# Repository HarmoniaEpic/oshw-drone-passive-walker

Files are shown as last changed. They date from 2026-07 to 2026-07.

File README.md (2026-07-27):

# Drone-Stabilized Passive Dynamic Walker（ドローン安定化受動歩行機）

**An open-source hardware concept: a McGeer-type passive dynamic walker whose
inverted-pendulum instability is converted into stable upright-pendulum
oscillation by an overhead stabilizing wrench — active thrust (Gen‑1) or
partial buoyancy (Gen‑2/3) — while the walking energy itself comes from
passive pendulum dynamics.**

> "A non-flying airship with legs."



---

## English summary

Passive dynamic walkers (McGeer 1990) are energy-efficient but unstable:
the stance phase is a divergent inverted pendulum. This project demonstrates,
in contact-accurate simulation (PyBullet, 1200 Hz event-driven control),
three generations of a machine that keeps the passive limit cycle intact and
stabilizes **attitude only** from above the virtual pivot point:

| Gen | Stabilizer | Propulsion | Key result |
|-----|---|---|---|
| 1 | Quadrotor attitude PD (**zero altitude support**, KZ=0) | Horizontal thrust (KV≥4–5) | 10 strikes / 8 s / 0.32 m/s sustained walking |
| 2 | Passive buoyancy (spherical He envelope on mast) | Azimuth ducted fan pair | Operating window **37–94 %W**; gait collapses by ground-force loss (~98 %W) *before* float-off (102 %W) |
| 3 | Passive buoyancy (airship hull + cruciform tail damping) | Azimuth ducted fan pair | 52 %W recommended; tail adds pitch/yaw damping & weathervane potential |
| 4 | **Mass geometry only** (water-ballasted feet, h_com < R, one-way "half-kamaboko" rocker soles) | Water transfer between feet + pump-charged drive bellows through a clock-escapement crank | 6 steps / +2.17 m / 40 s on flat ground, zero falls, body pitch within ±0.4°; crank quantized to half-turns |
| 5 | Mass geometry + "kamae" stance (crank-mounted tanks settle into a one-foot-raised ready pose) | **Water transfer only** — tanks ride the crank, hollow arms are the conduit, hub pump/valve; the whole body somersaults over the stance leg (dankaeri-faithful) | Fall-free 90 s / +0.43 m conservative gait (2 flips then parks); fast mode +1.93 m / 17.8 s (0.11 m/s); root limitation identified: uncontrolled leg attitude |
| 6 | Mass geometry + **gear-locked parallelogram legs** (each leg guided by two same-phase cranks 0.20 m apart; a 3-gear train on the leg locks the linkage through its dead center) | Water transfer only — the tank crank alone somersaults, the body stays upright; phase-synchronized transfer (SETTLE→CHARGE→FLIP) | **Zero falls over the whole pump range** (Q 0.15–0.50); best 18 steps / +2.42 m / 90 s, exact kinematic stride 2·RC = 0.134 m/step, body pitch ≤ 7° |

Distinct from BALLU (UCLA, buoyant body anchored by feet; patent application
US2018/0370040A1 **abandoned 2021**): here buoyancy is deliberately partial
(≈52 % of weight) so the legs stay loaded and heel-strike pendulum dynamics
— the energy mechanism — survive.

Everything here is simulation-validated design data: CAD, engineering
drawings, physics/control source, gait trajectories, and videos. No physical
prototype has been built yet — treat the BOM as a reference design.

## コンセプト（日本語）

受動歩行の振り子効率をドローンに持ち込み、倒立振り子の発散モードを
「上の支点から吊られた正立振り子」の振動モードに転換する。核心は3点：

1. **姿勢のみの上方安定化** — 高度支持ゼロ（KZ=0）でも歩行が成立する。
   安定化は帯域（Gen‑1）または浮心配置の幾何（Gen‑2/3）で払い、エネルギーでは払わない。
2. **部分浮力の適正窓** — 浮力37〜94%W。下限は姿勢発散、上限は浮上（102%W〜）より
   先に来る**接地力喪失による歩容崩壊**（98%W〜）。推奨52%Wで脚に体重の約半分を残し
   摩擦余裕を確保する。
3. **水平推力＝坂の代替** — ヒールストライク損失の補填はファンの水平推力
   （機械仕事0.1W級）のみ。同機体の単独飛行（誘導パワー約186W）に対し3〜4桁小さい。

## Repository layout

```
hardware/
  cad/        FreeCAD sources (.FCStd) + neutral STEP exports, Gen 1–6
  drawings/   A4 engineering drawings (PDF): assembly + parts, 21 sheets
sim/          Physics & control source of truth (PyBullet) + recorded gaits
  walker_pybullet.py   Gen-1  (usage: python walker_pybullet.py out.json <KZ> <KV>)
  walker_balloon.py    Gen-2  (usage: python walker_balloon.py out.json <B_N> [KV])
  walker_airship.py    Gen-3  (usage: python walker_airship.py out.json <B_N> [KV])
  walker_dankaeri5.py  Gen-4  (usage: python walker_dankaeri5.py out.json SLOPE_DEG
                       PUMP_PA [F_WIND] [E_MIN] [M_W] [P_BEL] [V_MAXB];
                       walker_dankaeri4.py is the earlier Gen-4 iteration)
  walker_gen5.py       Gen-5  (usage: python walker_gen5.py out.json SLOPE_DEG
                       Q_PUMP [M_W] [OM_V] [T_END] [R_T] [D_EXTRA] [BRAKES]
                       [C_CRK] [X_TOE] [Q_LIM] [FLIPLOCK] [R_TOE] [FOOT_REV])
  walker_gen6.py       Gen-6  (usage: python walker_gen6.py out.json SLOPE_DEG
                       Q_PUMP [M_W] [OM_V] [T_END] [R_T] [D_EXTRA] [-] [C_CRK]
                       [X_TOE] [-] [-] [R_TOE] [FOOT_REV] [PHASECTL] [DZ_T]
                       [RATCHET] [RC] [SLACK] [HEEL_HX]; reference config:
                       0 0.30 1.2 2.0 90 0.355 0.30 0 0.30 0.10 0 0 0.55 0 1
                       0.290 1 0.07 0.15 0.14)
  walk_traj_*.json     gait logs (base pose, joint angles, contact forces)
docs/         Concept note, per-generation design documents, BOM
media/        Walking videos (one per generation)
viz/          Blender visualization rigs (kinematic playback of sim output)
LICENSES/     Full license texts
```

## Reproducing the results

```
python -m venv pybullet-venv
pybullet-venv/bin/pip install pybullet numpy
pybullet-venv/bin/python sim/walker_pybullet.py out.json 0 5     # Gen-1: KZ=0, KV=5
pybullet-venv/bin/python sim/walker_balloon.py  out.json 13      # Gen-2: B=13 N
pybullet-venv/bin/python sim/walker_airship.py  out.json 13      # Gen-3: B=13 N
```

Each run prints strike count, distance, max pitch and mean fan force, and
writes a 60 Hz trajectory JSON. The Blender rigs in `viz/` replay these
trajectories as kinematic keyframes (Blender is visualization only; the
physics source of truth is `sim/`).

## Licensing（3層構成）

| Layer | Files | License | SPDX |
|---|---|---|---|
| Hardware design | `hardware/**` | CERN Open Hardware Licence v2 — Strongly Reciprocal | `CERN-OHL-S-2.0` |
| Source code | `sim/**` | MIT | `MIT` |
| Documentation & media | `docs/**`, `media/**`, `README.md` | Creative Commons BY-SA 4.0 | `CC-BY-SA-4.0` |

Full texts in [`LICENSES/`](LICENSES/). When adding files, put an SPDX
header in each source file, e.g. `# SPDX-License-Identifier: MIT`.

## Prior art & defensive publication

This design is published as open-source hardware; **no patent will be
sought**, and this repository (archived with a DOI on Zenodo — see
`docs/DEFENSIVE_PUBLICATION.md`) serves as defensive prior art for the
concepts listed above.

Key prior art acknowledged:

- T. McGeer, "Passive Dynamic Walking," *IJRR* 9(2), 1990.
- S. Collins, M. Wisse, A. Ruina, "A Three-Dimensional Passive-Dynamic
  Walking Robot with Two Legs and Knees," *IJRR* 20(7), 2001.
- H.-M. Maus et al., "Upright human gait did not provide a major mechanical
  challenge for our ancestors," *Nature Communications* 1:70, 2010
  (virtual pivot point).
- UCLA RoMeLa, BALLU / BALLU2 (buoyancy-assisted biped);
  US2018/0370040A1 (abandoned 2021), WO2017/087987A1.
- Traditional karakuri "dankaeri" tumbling doll (liquid-shift somersault
  automaton) — mechanism reference for Gen-4/5/6.
- Classic parallel-crank (side-rod) motion — locomotive coupling rods and
  wind-up walking toys — and gear-synchronized parallelogram guidance:
  mechanism references for the Gen-6 leg-attitude lock.

## Status / OSHW

- [x] Zenodo DOI: [10.5281/zenodo.21629977](https://doi.org/10.5281/zenodo.21629977)
- [ ] OSHWA self-certification (JP): *pending — apply after first tagged release*
- Simulation-validated; no physical build yet. Real-scale note: B=13 N of
  helium lift requires ≈1.3 m³ (sphere Ø≈1.4 m); the modeled envelopes are
  intentionally idealized.

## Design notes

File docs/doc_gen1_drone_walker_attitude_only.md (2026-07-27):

# 第1世代：クアッドロータ安定化受動歩行機（attitude-only 構成）

**対応ファイル**: `gen1_drone_walker_attitude_only.blend` / `walker_pybullet.py` /
`walk_traj_attitude_only.json` / `drone_walker_attitude_only.mp4`

---

## 1. 概要

受動歩行機（膝付き4脚・McGeer型）の股関節台座にクアッドロータを一体化した初代構成。
「移動エネルギーは脚の振り子力学、安定化はドローンの飛行制御」という役割分担を
最初に実証した世代。段階的な補正削減試験により、ドローンの必須機能が
**姿勢制御と水平推力（エネルギー補給）のみ**であることを特定した。

## 2. 機体構成

| 要素 | 仕様 |
|---|---|
| トルソ | 股関節車軸＋矩形台座＋対角4アーム先端ロータ（低重心配置・台座上面は上半身搭載用に確保）、1.2 kg |
| 大腿 | 各 0.22 kg、長さ 0.40 m、股関節はフリーヒンジ（完全受動） |
| 下腿 | 各 0.20 kg、長さ 0.40 m、膝は反張ストッパ（+0.08 rad）付き |
| 足 | 半径 0.12 m の円弧足（脚長の15%）、下腿軸から前方 0.04 m オフセット |
| 総質量 | 2.24 kg（総重量 22.0 N） |

**設計の要点**
- 円弧足の前方オフセットは床反力線を膝軸の前に通し、立脚中の膝を
  ストッパへ押し付け続ける座屈防止機構（実機文献と同じ手法）
- 外側大腿ペアの連結は股関節軸上を跨ぐヨークアーチとし、内脚可動域との干渉を回避

## 3. 制御アーキテクチャ（イベント駆動・1200 Hz）

| 系 | 実装 |
|---|---|
| センサー | 足別接地法線力、関節角・角速度 |
| ヒールストライク判定 | 遊脚接地力 > 8 N かつ 遊脚股関節角 < −0.08 rad かつ 遊脚時間 > 0.2 s |
| 膝ラッチ | 立脚＝強保持（300 N·m 上限で 0.08 rad へ）。遊脚＝トーオフ折りパルス（0.18 s、上限 1.5 N·m）→ 自由屈曲 → 股関節角 −0.10 rad 通過で再伸展 |
| ドローンFC | 姿勢PD（kp 80 / kd 10）＋速度追従（kv 5、目標 0.38 m/s）。**高度支持なし（KZ=0）** |

## 4. 実験結果（最終構成）

- **10歩連続・8秒・転倒なし**、平均 0.32 m/s
- 歩行周期 0.72 / 0.91 s の交互（周期2リミットサイクル）
- 平均推進力 0.31 N、推進の機械仕事 0.1 W 級
- 補正削減スイープの結論：高度支持は 400 N/m → 0 まで完全撤廃可能。
  速度補給ゲイン KV ≥ 4–5 が下限（KV=3 では高度支持の量に関係なく2歩で転倒）
  ＝ 平地では推力がヒールストライク損失を補填するエネルギー源であることの定量的裏付け

**エネルギー比較**：同機体を単体飛行させる場合の誘導パワー約186 W（電気入力 ~265 W）に対し、
歩行アシストの機械仕事は3〜4桁小さい。実機換算でも10〜50倍の節約見積り。

## 5. 開発過程で確定した知見

1. 遊脚が支持脚と平行になる瞬間の接地（toe scuffing）は直脚系の本質的欠陥で、
   膝機構＋トーオフ折りパルスがなければ2歩目が出ない
2. 一定剛性の膝バネでは立脚座屈防止と遊脚屈曲が両立不可能 → 状態依存ラッチが必須
3. 発進は死点（静的平衡）からではなく、関節角速度込みの歩行中間状態から与える
4. 定速クランプは振り子交換を殺す — 速度制御は平均への緩い補給に留める

## 6. 制約・注意

- 姿勢安定は能動制御（FC帯域）に依存。制御停止＝即転倒（発散時定数 ~0.27 s）
- .blend はキネマティック再生の可視化リグ。物理の原本は `walker_pybullet.py`
  （KZ / KV を CLI 引数で変更可能：`python walker_pybullet.py out.json <KZ> <KV>`）
- PyBullet モデルは脚ペアを面内1本に縮約した2D拘束相当（横方向は代理拘束）

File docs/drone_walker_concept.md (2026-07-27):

# ドローン安定化受動歩行機 — コンセプトノート

**日付**: 2026-07-27
**状態**: シミュレーション実証済み（PyBullet 1200 Hz / Blender 可視化）

---

## 1. 概要

受動歩行機（passive dynamic walker）の上部にマルチロータを一体化し、
**移動エネルギーは脚の振り子力学、安定化はドローンの飛行制御**という分担で
平地を歩行させる機体コンセプト。シミュレーションで持続歩行（10歩・8秒・転倒なし）を実証した。

## 2. 着想の核

### 2.1 振り子効率のドローンへの導入

ローター揚力は重力と常時対抗し続けるため誘導パワーを払い続ける。
一方、歩行は運動エネルギーと位置エネルギーを振り子交換で往復させ、
支払いはヒールストライクの衝突損失のみ。
飛行・歩行ハイブリッド機の歩行側を**完全受動脚**とすることで、
歩行モードのアクチュエータコストをほぼゼロにできる。

### 2.2 倒立振り子の「正立振り子化」（本コンセプトの肝）

- 立脚は倒立振り子であり、固有値 +√(g/ℓ) の発散モードを持つ
  （ℓ≈0.72 m → 発散時定数 ≈ 0.27 s）
- 重心**上方**に搭載したドローンが安定化レンチ（姿勢トルク＋復元力）を
  供給すると、発散モードは振動モードに転換され、系は「上の支点から
  吊られた正立振り子」と等価な安定構造になる
- ヒト歩行の **Virtual Pivot Point**（Maus et al. 2010）— 床反力線を
  重心上方の一点に通して体幹を正立振り子として安定化する機構 — の
  **物理的実装**と位置づけられる
- 発散時定数 0.27 s ≒ 必要制御帯域は数 Hz。クアッドFCの姿勢ループ
  （数百 Hz）で余裕をもって抑えられる。**不安定の抑制は力ではなく
  帯域の勝負であり、帯域はエネルギーをほぼ消費しない**

## 3. 実証構成

### 機体（Blender で設計、質量・寸法を PyBullet に移植）

| 要素 | 仕様 |
|---|---|
| トルソ | 股関節軸上の矩形台座＋対角4アーム先端ローター（上半身搭載スペース確保）、1.2 kg |
| 脚 | 大腿0.22 kg＋下腿0.20 kg ×2、脚長0.8 m（大腿0.4／下腿0.4） |
| 膝 | 反張ストッパ（+0.08 rad）付きヒンジ。McGeer型 |
| 足 | 半径0.12 mの円弧足（脚長の15%、Collins機準拠）、前方4 cmオフセット（膝座屈防止） |
| 股関節 | **完全受動**（フリーヒンジ） |

### 制御（イベント駆動、1200 Hz）

| 系 | 実装 |
|---|---|
| センサー | 足別接地法線力（ロードセル相当）、関節角・角速度（エンコーダ相当） |
| 歩行状態機械 | 遊脚接地力 > 8 N かつ 股関節角 < −0.08 rad → ヒールストライク→立脚/遊脚交代 |
| 膝ラッチ | 立脚=強保持（McGeer吸盤ラッチ相当）／遊脚=トーオフ折りパルス（0.18 s・上限1.5 N·m）→自由屈曲→股関節角ゲートで再伸展 |
| ドローンFC | 姿勢PD（維持）＋水平推力（平均速度の緩い補給）。**高度支持はゼロまで削減可能** |

### 結果（最終構成：姿勢＋水平推力のみ）

- 10歩連続・8秒・転倒なし、平均速度 0.32 m/s
- 歩行周期 0.72／0.91 s の交互（周期2リミットサイクル — 受動歩行の既知現象）
- 遊脚膝屈曲 最大 −1.0 rad、腰高さ変動 0.824–0.837 m（自然なボールト）
- 平均推進力 **0.31 N**、推進の機械仕事 **0.1 W級**

## 4. エネルギー比較（総質量 2.24 kg・0.32 m/s）

| モード | パワー | 輸送コスト COT |
|---|---|---|
| 単体飛行（ホバー、運動量理論・4×r10cmロータ） | 誘導186 W／電気入力 約265 W (FoM 0.7) | 26.5 |
| 歩行アシスト（機械仕事） | 0.1 W級 | 0.001–0.01 |
| 歩行アシスト（実機見積り：制御権限用ベース推力・プッシャープロップ・アビオニクス込み） | 5–30 W | — |

**実機換算でも1〜2桁、機械仕事ベースで3〜4桁の節約。**
飛行10分の機体が歩行モードで2〜8時間動ける計算になる。
（参考：Collins機は4.8 kgで重力パワー1.3 W — 本結果と整合）

## 5. 削減試験で得た定量的知見

| 高度支持 KZ | 速度補給 KV | 結果 |
|---|---|---|
| 120→10 | 4–6 | 完走 |
| **0** | **5–6** | **完走（姿勢＋推力のみ）** |
| 任意 | ≤3 | 2歩で転倒 |

- 高度支持は**完全撤廃可能** — ボールトの上下動は脚が自前で生成
- 譲れないのは**エネルギー補給**（KV ≥ 4–5）。平地では推力が斜面の
  位置エネルギーを代替する、という当初仮説の定量的裏付け

## 6. 開発過程で確定した設計要件（文献照合済み）

1. **円弧足は脚長の~15%半径、前方オフセット付き** — オフセットは床反力線を
   膝の前に通し、立脚膝をストッパに押し付け続ける座屈防止機構
2. **膝ラッチは状態依存が必須** — 一定剛性のバネでは立脚座屈防止と遊脚屈曲が
   両立不可能（McGeerの吸盤、Wisseのラッチの理由）
3. **トーオフの膝折りインパルスが第2歩目以降の生命線** — 遊脚が平行位置で
   接地する「toe scuffing」は直脚系の本質的欠陥で、膝＋折りパルスで解消
4. **発進は死点からではなく歩行中間状態から**（関節角速度込み）。
   実機文献でも「不適切な初期条件が失敗の主因」（成功率80%）
5. 定速クランプは振り子交換を殺す — 速度制御は「平均の緩い補給」に留める

## 7. 今後の課題

- 外乱応答試験（押し・段差）— 「正立振り子化」の安定余裕の定量化
- 速度指令追従（ドローン推力によるギア変更）
- 3D化（横方向・ヨー）: 現構成の4脚フレームは2D拘束。Collins機の
  横揺れ結合・カウンタースイングアームが参考になる
- 台座上への上半身搭載（マニピュレータ等）と質量変動への適応
- 実機化：膝ラッチ機構（電磁ラッチ or 小型サーボ）、水平推力用
  プッシャープロップ、姿勢はFC標準機能で足りる

## 8. 参考文献

- T. McGeer, "Passive Dynamic Walking," IJRR 9(2), 1990
- S. Collins, M. Wisse, A. Ruina, "A Three-Dimensional Passive-Dynamic
  Walking Robot with Two Legs and Knees," IJRR 20(7), 2001
  （プロジェクト内 PDF: Collins_Wisse_Ruina_2001_3D_passive_walker.pdf）
- S. Collins, A. Ruina, R. Tedrake, M. Wisse, "Efficient Bipedal Robots
  Based on Passive-Dynamic Walkers," Science 307, 2005
- H.-M. Maus et al., "Upright human gait did not provide a major mechanical
  challenge for our ancestors," Nature Communications 1:70, 2010（Virtual Pivot Point）
- M. Garcia, A. Chatterjee, A. Ruina, "Some Results in Passive-Dynamic Walking"

## 9. 成果物一覧

| ファイル | 内容 |
|---|---|
| `walker_pybullet.py` | 物理・制御・テレメトリ（KZ/KV をCLI引数化） |
| `walk_traj_attitude_only.json` | 最終構成の軌道＋センサーログ |
| `gen1_drone_walker_attitude_only.mp4` | 最終構成の歩行動画 |
| `drone_walker_pybullet_walk.mp4` | 補正大構成の比較動画 |
| `drone_passive_walker.blend` | 機体モデル＋歩行アニメーション |

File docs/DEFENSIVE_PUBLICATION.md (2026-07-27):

# 防衛公開の手順（Defensive Publication Checklist）

方針: **特許出願はしない**。第三者による権利化を防ぐため、公知日を証明できる形で
本設計を公開する。以下は順序どおりに実行すること。

## 0. 公開前の最終確認

- [ ] リポジトリに固有名・個人情報・非公開にしたい情報が残っていないか確認
- [ ] J-PlatPat で周辺特許の最終確認（キーワード: 受動歩行 / 浮力 姿勢安定 /
      脚式ロボット 気球、分類: B62D 57/032, B64B）
- [ ] 3層ライセンス（CERN-OHL-S-2.0 / MIT / CC-BY-SA-4.0）の表記が
      README と LICENSES/ に揃っているか

## 1. GitHub 公開 + タグ付きリリース

- [ ] GitHub にパブリックリポジトリ作成（例: `drone-passive-walker`）
- [ ] 本ディレクトリ一式を push
- [ ] `v1.0.0` タグでリリース作成（リリースノートに核心3点を明記:
      ①姿勢のみ上方安定化による倒立→正立振り子転換
      ②部分浮力の適正窓 37–94%W と接地力喪失が浮上に先行する知見
      ③水平推力による坂の代替＝エネルギー補給の分離）

## 2. Zenodo で DOI 取得（公知日の証明）

- [x] zenodo.org に GitHub 連携でログイン → 対象リポジトリの連携を ON
- [x] リリースを切ると自動でアーカイブされ DOI が発行される
- [x] 発行された DOI を README の Status 欄と CITATION.cff に記入
- [ ] メタデータ: resource type = Software / Dataset、キーワードに
      "passive dynamic walking", "buoyancy stabilization", "open source hardware"

## 3. （任意・推奨）日本語での確実な先行技術化

- [ ] 発明推進協会「公開技報」に技術開示を掲載（審査官が確実に参照する媒体）
- [ ] または IP.com Prior Art Database（英語圏向け）

## 4. arXiv プレプリント（cs.RO）

- [ ] docs/ のコンセプトノートを英語論文体裁に整えて投稿
- [ ] 図は hardware/drawings/ と media/ から流用、Zenodo DOI を引用

## 5. OSHWA 自己認証

- [ ] certification.oshwa.org で申請（要: 公開リポジトリURL、ライセンス表記、
      第三者知財非侵害の宣誓）
- [ ] 取得した JP 番号を README に記載、ギアマークを図面表題欄に追加

## 6. コミュニティ発表

- [ ] Hackaday.io プロジェクトページ（英語、動画埋め込み）
- [ ] Maker Faire Tokyo / NT 系イベント出展検討
- [ ] 国内学会（ROBOMECH 等）はステップ4の後でも新規性上問題なし

## 記録

| 日付 | 事項 | 証跡 |
|---|---|---|
| | GitHub 初回公開 | commit hash: |
| 2026-07-28 | Zenodo DOI 発行 | DOI: 10.5281/zenodo.21629977 |
| | 公開技報掲載 | 技報番号: |

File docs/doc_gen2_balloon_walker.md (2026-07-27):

# 第2世代：バルーン受動安定歩行機（球形気嚢＋アジマスファン）

**対応ファイル**: `gen2_balloon_walker.blend` / `walker_balloon.py` /
`walk_traj_balloon.json` / `balloon_walker_walk.mp4`

---

## 1. 概要

第1世代で「ドローンの必須機能は姿勢制御と水平推力のみ」と判明したことを受け、
**姿勢制御を能動（FC）から受動（浮力）へ置き換えた**世代。
マスト頂部のヘリウム気嚢が重心上方に浮力を供給し、機体が傾くと自動的に
復元トルクが生じる（船舶のメタセンタ安定と同原理）。倒立振り子の発散モードが
「上の支点から吊られた正立振り子」の振動モードに転換される。

推進は台座両脇のアジマス式ダクテッドファン1対に縮約。掘削船の動的位置保持や
飛行船の推力偏向と同じ「支持は別系統・推進器は位置と向きの調整のみ」の思想。

## 2. 機体構成（第1世代からの変更点）

| 要素 | 仕様 |
|---|---|
| 気嚢 | 球形、マスト頂部（股関節上方 1.55 m）に搭載。浮力 B は試験パラメータ |
| 気嚢系質量 | 0.25 kg（外皮＋マスト、取付点に集中） |
| 推進 | アジマス式ダクテッドファン×2（車軸端アウトリガー y=±0.36、水平推力のみ） |
| ロータ | クアッド4基 → 撤去 |
| 総質量 | 2.49 kg（総重量 24.4 N） |
| 制御 | **能動姿勢制御ゼロ**。ファンは平均速度の緩い補給（kv 5）のみ。ヨー減衰・横方向は4脚フレーム代理拘束 |

脚系（膝ラッチ・円弧足・イベント駆動歩行状態機械）は第1世代と同一。

## 3. 適正重量試験（本世代の主題）

浮力 B を総重量比 0〜102% で掃引した結果：

| 浮力比 | 挙動 | 決定要因 |
|---|---|---|
| 0〜33% | 転倒（ピッチ発散 7〜35°） | 復元トルク B·h が倒立振り子の発散に不足 |
| **37〜94%** | **9歩完走** | 適正窓。浮力増でピッチ振れ 3.5°→1.8°、ファン推力 0.57→0.23 N と単調改善 |
| 98〜99% | 転倒しないが1歩のみ | 接地力喪失で歩容が消滅（滑走状態） |
| ≥102% | 浮上 | 浮力＞重量 |

**推奨適正値：B = 13 N（53%W）** — ピッチ±3.0°、ファン平均 0.52 N、
脚に体重の47%が残り摩擦余裕（外乱耐性）を確保。

実寸換算：ヘリウムの正味揚力 ≈ 1.02 kg/m³ より、B=13 N には約 1.3 m³
（球なら直径約 1.4 m）の気嚢が必要。機高 0.85 m に対して大きく、
実機化では軽量化または細長形状の検討課題（→第3世代）。

## 4. 本世代で得た知見

1. 姿勢安定はエネルギーではなく**復元トルクの幾何**で賄える。消費電力ゼロ、
   制御系停止時も姿勢が保たれるフェイルセーフ性を獲得
2. 「浮きすぎ」の失敗は浮上（102%〜）より先に**歩容の崩壊**（98%〜）として現れる
3. 残る消費はファンの水平推力（平均 0.3〜0.6 N、機械仕事 0.2 W 級）のみ

## 5. 制約・既知の問題

- **マストとヨークアーチの幾何干渉**：センターマストが外脚連結ヨークの掃引域を
  通る設計欠陥がこの世代には残っている（第3世代の門型マストで解消）
- 球形気嚢は回転減衰を持たず、振り子スロッシュの減衰は空気抵抗頼み
- .blend は可視化リグ。物理の原本は `walker_balloon.py`
  （`python walker_balloon.py out.json <浮力N> [KV]`）

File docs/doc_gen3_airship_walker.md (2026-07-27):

# 第3世代：飛行船型歩行機（回転楕円体気嚢＋十字尾翼）

**対応ファイル**: `gen3_airship_walker_face.blend` / `walker_airship.py` /
`walk_traj_airship.json` / `airship_walker_face.mp4`（旧版 v1/v2 動画あり）

---

## 1. 概要

第2世代の球形気嚢を**飛行船型（回転楕円体）気嚢＋船尾十字尾翼**に発展させた
現行世代。「足の生えた飛ばない飛行船」。浮力による受動姿勢安定という
第2世代の原理はそのままに、細長気嚢による前後方向性と、尾翼による
回転減衰・風見安定性を獲得した。

## 2. 機体構成（第2世代からの変更点）

| 要素 | 仕様 |
|---|---|
| 気嚢 | 回転楕円体（全長 2.2 m × 直径 0.9 m、フィネス比 2.4）、長軸を進行方向に一致 |
| 浮心 | 気嚢は前後対称のため幾何中心＝浮心。**浮心を機体重心の鉛直上方に配置**し静的トリムをゼロに（尾翼質量の後方偏りは機首バラストで相殺する前提で、質量集中点を浮心に一致させて模擬） |
| 尾翼 | 船尾に十字配置4枚（水平安定板2＋垂直安定板2）。船尾断面半径 0.27 m の外側へ翼幅 0.34 m を張り出し |
| マスト | **門型（ポータル）構造**：垂直支柱2本を外脚ヨーク可動域（y=±0.22）の外側 y=±0.30 に配置、掃引頂部の上方 z=1.04 にクロスバー、斜材で頂点集約後に単管で気嚢腹部へ。第2世代の干渉問題を解消し、三角トラス化で剛性も向上 |
| 気嚢系質量 | 0.30 kg（外皮＋尾翼＋マスト） |
| 総質量 | 2.54 kg（総重量 24.9 N） |
| 外装 | 気嚢・尾翼は白。機首側面左右に円形マーキング1対（装飾） |

## 3. 物理モデルの追加要素

| 項目 | 実装 |
|---|---|
| 気嚢回転慣性 | 細長胴体のピッチ／ヨー慣性を気嚢リンクに設定（0.02 / 0.07 / 0.07 kg·m²） |
| 尾翼減衰 | ピッチ・ヨー角速度に比例する減衰トルク（各 0.5 N·m·s/rad）。気嚢振り子スロッシュを抑制 |
| 胴体抗力 | 並進抗力係数を球形時の 0.35 → 0.80 N·s/m に増加 |

## 4. 実験結果

| 浮力 | 結果 |
|---|---|
| 10 N（40%W） | 転倒 — 気嚢の質量・慣性増で適正窓下限が第2世代（37%）より上昇 |
| **13 N（52%W）** | **9歩完走**、ピッチ±3.4°、ファン平均 0.53 N |
| 16 N（64%W） | 9歩完走、ピッチ±2.9° |

推奨適正値は引き続き**浮力 ≈ 52%W**。歩容・エネルギー特性は第2世代とほぼ同等で、
形状変更のコスト（慣性増による窓下限上昇）と利得（尾翼減衰・方向性）が拮抗する。

## 5. 尾翼の位置づけ

歩行速度 0.3 m/s 程度の屋内条件では、尾翼は主として**回転減衰器**として働く。
本領は屋外・3D化した際の**風見安定**（機首を相対風に向ける復元）であり、
第2世代の球形気嚢では原理的に得られない方向安定性を仕込んだ装備である。

## 6. 制約・今後の課題

- 実寸の気嚢体積：浮力 13 N には約 1.3 m³ が必要。モデルの外形（約 0.93 m³ 相当）は
  やや理想化されており、実機ではフィネス比を保ったまま全長を伸ばすか機体軽量化が必要
- 横方向・ヨーの動力学は4脚フレーム相当の代理拘束で2D化されている。
  3D化時は尾翼・アジマスファンのヨー制御が本格的に効いてくる
- 外乱応答（突風・押し外乱）試験は未実施
- .blend は可視化リグ。物理の原本は `walker_airship.py`
  （`python walker_airship.py out.json <浮力N> [KV]`）

## 7. 世代系譜まとめ

| 世代 | 姿勢安定 | 推進 | 特徴 |
|---|---|---|---|
| 第1（クアッド） | 能動（FC姿勢PD） | ロータ推力 | 帯域で安定化。制御停止＝転倒 |
| 第2（球形気嚢） | **受動（浮力）** | アジマスファン×2 | 安定化の消費電力ゼロ化 |
| 第3（飛行船型） | 受動（浮力）＋尾翼減衰 | アジマスファン×2 | 方向性・風見安定・干渉解消 |

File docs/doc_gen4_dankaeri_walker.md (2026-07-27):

# 第4世代：段返り式水圧歩行機（半かまぼこ足＋重錘時計アーキテクチャ）

**対応ファイル**: `gen4_dankaeri_walker.blend` / `walker_dankaeri4.py`（系列v4:
クランク実リンク・油圧線・脱進の基礎実装）/ `walker_dankaeri5.py`（系列v5:
連続歩行達成版）/ `dankaeri_walker_walk.mp4`（歩行動画）/
`gen4_walker.FCStd`＋図面PDF 4葉（gen4_assembly / gen4_leg_truss /
gen4_foot_unit / gen4_crank_unit）。

---

## 1. 概要

からくり人形「段返り童子」——体内の液体（水銀）の移動で重心を移し階段を
宙返りで降りる——の**平地歩行版**。第1〜3世代が追求した「姿勢安定装置」系列
（能動FC→受動浮力）の帰結として、本世代は**装置そのものを消滅**させた：
質量の大半を水として足元に集中させ（h_com=0.288m ＜ つま先弧R=0.30m）、
機体は質量配置の幾何だけで転倒しない。

水が全役職を演じる：**質量**（安定）、**重錘**（駆動エネルギー）、
**移送体**（重心シフト＝推進）、**作動流体**（ベローズ駆動）。外部入力は
マイクロポンプの電力のみで、下り坂では原理的にゼロにできる。

## 2. 機体構成

| 要素 | 仕様 |
|---|---|
| 脚 | 膝なしトラスカラム2本（同一部品、長さ0.695m）。上端をクランクで結合 |
| クランク | 半径RC=0.07m・軸高0.84m。1反転＝半回転＝1歩。180°デテント円盤付き |
| 股関節 | 貫通ピン＋**連続回転ゴンドラ軸受**（フェリスホイールの客車と同じ） |
| 足 | **半かまぼこ**：踵側平底0.20m＋足中心を接線とするつま先弧R=0.30m。接地幾何の機械式ダイオード（後方転がり不可・前方のみ閾値つきで転がる） |
| 足板 | 二重フレーム＋4隅コイルバネ、ストローク50mm。着地衝撃吸収兼ラック駆動源 |
| 水嚢 | バネ上（上板）のカーゴ配置＝圧力中立。総水量1.2L、低位短ホース（内径28mm級）で足間直結 |
| ラック＆ピニオン | 実比 r=ストローク/π≈16mm（1ストローク＝半回転）。ピニオンはフリーホイール内蔵 |
| ポンプ | 足置きマイクロポンプ対（12〜16kPa・0.15L/s級）。送水方向は**クランク軸直結ロータリーバルブ**で自動転流 |
| 駆動ベローズ | バネ付勢蛇腹（受圧0.008m²）。ラッチ中に充圧、解放でラックを押す。**12kPa×0.28L/発**が調律値 |
| 総質量 | 2.80kg（うち水1.2kg＝43%、足元系合計で約7割） |

## 3. 動作原理 — 重錘式振り子時計との対応

| 時計 | 本機 |
|---|---|
| 重錘（分銅） | ポンプが充圧する駆動ベローズ |
| 香箱・輪列 | ベローズ→ラック→ピニオン→クランク |
| ガンギ車＋アンクル | フリーホイール＋180°デテント＋解放ラッチ |
| 振り子の等時性 | 水移送の時定数（ホース径・ポンプ流量が刻む） |
| 文字盤 | 前進距離 |

**1歩のサイクル**：ラッチ（＝ロータリーバルブ閉）中にポンプがベローズを充圧
→ 並行して水が前足へ転流（重心前進、平底ダイオードが前進分だけ保存）
→ **段返り条件（水移りきり ∧ 充圧完了）で解放**
→ ベローズがラックを押しクランクがスナップ半回転（後脚＝軽い側が前へ）
→ 遊脚が踵平底で着地しキャッチ → デテント着座・再ラッチ → 次周期。

## 4. 実験結果（PyBullet, 1/2400s）

- **転ばない性**：h_com<R＋平底ダイオードにより、調律版は全40秒試験で転倒ゼロ
- **半かまぼこの効果**：対称ロッカーで毎回発生した後方整定ロール・後方雪崩が
  根絶され、水装填だけで**初の系統的前進**（+0.10〜0.12m）が出現
- **間欠スナップ回転**：クランクは「溜め→スナップ→デテント着座」の階段波形で
  0→π→2π→…→**8πまで完全量子化**（等速回転にはならない——設計意図どおり）
- **連続歩行**：**15kPa×0.15L調律で6歩/40秒・前進+2.17m・転倒ゼロ**
  （平均5.4cm/s）。世界座標ピッチは全区間±0.4°以内。線量を増すと
  デテント通過後の捕捉に失敗して転倒（脱進機の線量調律問題）
- **開発時の重大な計測教訓**：クランク駆動トルクを関節に与えると反作用が
  自由浮遊の軸体に落ち、軸体が逆回転してクランク相対角が「偽の反転」を
  量産した（機体は世界座標で宙返りしていた）。反作用を実機の荷重経路
  （ラック→立脚足）へ明示的に配線し直して初めて上記の正しい歩行が得られた。
  併せて、立脚股ブレーキは**ラッチ保持中のみ**係合（反転中はゴンドラ解放）が
  段返りの正しい順序であることも確定した

## 5. 開発で確定した知見

1. **板間加圧水嚢は設計矛盾**：荷重経路内の水嚢は立脚から水を追い出す＝
   アンカー質量集中と真逆。水嚢はバネ上カーゴ（圧力中立）が正解
2. **移送は水柱イナータンス（ρL/A）支配**：クランク上を越える長ホースは不成立。
   低位短ホース（0.4〜0.5m・太径）が必須。長ホース化はポンプ5〜10kPa増圧で可能
3. **対称ロッカーは双方向に転がる**ため後方雪崩・その場足踏みのアトラクタを作る。
   半かまぼこ（平底＋つま先弧）が制御パッチ3件を幾何1つで置換した
4. **準静的スロッシュがラックに流せる力は水の重量変化分（~6N）のみ**（0.1J/移送）。
   反転の壁（~2J）はベローズのような蓄圧アクチュエータでのみ越えられる
5. 脚は左右同一部品・股は連続回転軸受・立脚股は荷重連動ブレーキ——
   段返り人形の「宙返り中は剛体」の機械翻訳
6. （実装教訓）速度クランプ型の数値ラチェットは接触ジッタを回転に整流する
   （ファインマンのラチェット）。片側位置拘束バネ型が正しい

## 6. 制約・今後の課題

- ベローズ線量の調律（0.28〜0.4Lの間）・再ラッチ時の余剰圧ベント・着地減衰に
  よる正味歩幅の最適化（現状は歩間の後方スライドで正味前進が目減り）
- 下り坂の純受動モード（ポンプゼロ）の成立確認と、斜面での線量自動減
- 3D化（横方向・旋回）、不整地試験（歩行書き戻し・動画化・OSHW追加・図面は完了）
- 実寸部品選定：ポンプ12〜16kPa・0.15L/s級、ベローズ受圧0.008m²、
  フリーホイール・ワンウェイクラッチの市販品調査

## 7. 世代系譜

| 世代 | 姿勢安定 | 推進エネルギー | 特徴 |
|---|---|---|---|
| 第1（クアッド） | 能動（FC姿勢PD） | ファン水平推力 | 帯域で安定化 |
| 第2（球形気嚢） | 受動（浮力） | ファン水平推力 | 安定化の消費電力ゼロ化 |
| 第3（飛行船型） | 受動（浮力＋尾翼） | ファン水平推力 | 方向性・風見安定 |
| **第4（段返り式）** | **質量幾何のみ（装置消滅）** | **水移送＋蓄圧ベローズ** | 水が質量・重錘・作動流体を兼任 |

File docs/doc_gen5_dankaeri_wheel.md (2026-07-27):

# 第5世代：段返り水車式歩行機（クランク・水移動一体化）

**対応ファイル**: `gen5_walker.blend`（Gen-4モデルからの改造）/ `walker_gen5.py`
（PyBulletシミュレータ）/ `gen5_gait_strip.png`（初歩行の時系列）/
`gen5_walker_walk.mp4`（保守型歩行の動画）。

---

## 1. 概要

Gen-4は「水は足元に固定し、駆動連鎖（ポンプ→ベローズ→ラック→ピニオン→
クランク）で反転を作る」構成だった。Gen-5は**水タンクをクランク腕の先端に
搭載し、中空腕を導管化**することで、駆動連鎖を丸ごと消滅させた。よりオリジナル
の段返り童子——体内の水銀が移動して体ごと返る——に忠実な系である。

クランク関節は完全受動（トルク制御なし）。唯一の作動は**ハブのポンプ・弁に
よるタンク間の水移送**であり、質量配置の変化だけが機体を歩かせる。

## 2. 機体構成（Gen-4からの差分）

| 要素 | 仕様 |
|---|---|
| クランク | 腕−45°傾斜・長さ0.32m。タンク取付は首部経由で軸線からオフセット |
| タンク | 2基、軸から(±0.355, ∓0.44, ±0.290)＝レバー半径0.459m。質量線はピン線の39°先行（C2同回転向き） |
| ポンプ・弁 | クランクハブ中央（回転側搭載：偏心ゼロ・油圧対称・回転シール不要） |
| 股関節 | 連続回転ゴンドラ軸受＋一方向コード（紐）＋フリーホイール（後方巻き戻し禁止） |
| 足 | 半かまぼこロッカー：踵平底＋**つま先弧R=0.40**（Gen-4の0.30から拡大）、脚軸より0.04前方оффセット、ゴム底（μ≈2.0） |
| 足バネ | K=1500 N/m（単脚支持31Nで底付き回避のため増強） |
| 撤去部品 | 足水嚢・足ポンプ・ラック・ピニオン・ベローズ・外部ホース・デテント爪 |
| 総質量 | 3.15kg（うち水1.2kg） |

**命名規約**: 進行方向+xに向かって+y側=左半身=_L。

## 3. 動作原理 — 段返り童子との対応

1. **構え（かまえ）**: タンクL満水時、クランクが約−30°に静定し、満水タンクは
   軸の15cm後方にぶら下がる。このとき**右足がピンごと前方斜め位置に浮上**
   （すりあし回避のクリアランス）。浮いた脚の重量が吊り平衡を手前で止める
   釣り合いが、次の一歩の方向も確定する。
2. **揚水**: ポンプが後方低タンクから前方高タンクへ移送（1歩あたりの主エネル
   ギー入力）。弁は高速回転中は凍結（人形の「反転中は水銀が動かない」）。
3. **反転**: 質量交差後、満水タンクが**低所で支点脇をすり抜ける振り子通過型**
   の半回転。人形の「重い頭は支点際・軽い側が返る」に対応。
4. **着地・交換**: 支持脚交換、ポンプが自動転流して再武装、C2対称で次の構えへ。

## 4. 実験結果（PyBullet, 1/2400s, 平地）

- **構えの安定性**: 延長腕構成で全試験パラメータ域（ロッカーオフセット
  0.02〜0.12、減衰0.02〜0.3、ブレーキ有無）において転倒ゼロ。
- **初歩行**: Q=0.15kg/sで2フリップ・+1.67m/22秒（のち転倒）。
- **保守型（転倒なし）**: R_toe=0.40・μ=2.0・Q=0.15で**90秒間転倒ゼロ・
  +0.43m・クランク+6.45rad**。ただし2歩後にポンプ規則由来の駐機状態あり。
- **高速型**: 前方移送規則＋フリーホイールラチェットで**+1.93m/17.8秒
  （0.11m/s＝Gen-4の2倍）**、ただし前方転倒あり。安定化は位相同期制御待ち。

## 5. 開発で確定した知見

1. **剛体ボールト型の一歩は幾何学的に不成立**: つま先支点→タンクの回転半径
   （約1.0m）が機体高を超え、50°で必ずタンクが接地する。振り子通過型が正解。
2. **吊りアセンブリは自己平衡する**: 水をいくら移しても機体重心の接地投影が
   ピン直上から動かず、線量が全量まで暴走する。対策は股の一方向コード
   （人形の紐）——「水銀の移動と手足のバランスがポイント」の後半の機構的意味。
3. **つま先弧半径のトレードオフ**: R>h_com(0.46)で前方転倒は根絶されるが
   推進も死ぬ（受け皿化）。R=0.40が転倒保護と推進の両立点。**踵の平底は
   不可侵**（逆転構成は後方雪崩−6mで即失格）。
4. **足の接地摩擦が歩幅を決める**: μ=0.9ではフリップ反動で立脚が後方スリップ
   し正味後退。μ=2.0（ゴム底）で正味前進に反転。
5. **クランク角の逆巻き禁止（フリーホイール）が位相を守る**: 導入で速度倍増。
6. **ポンプ方向の局所規則は駐機アトラクタを生む**: 「低→高」「前方へ」いずれも
   複数の安定駐機姿勢（後傾満水高・50/50均衡・前満水閉ループ）に嵌まる。
   歩行サイクル位相に同期した移送制御（クランク角連動ロータリーバルブの
   ソフトウェア版）が必要。
7. **書き戻し検品**: 宙返りは股まわり＝基部ごと回るため、基部ピッチを転倒判定に
   使ってはならない。足回り造形は正面視チェックも必須（横ズレ検出）。
8. **可視化**: 剛体タンクは変形させず、内部のWaterボックスの水位で水量を表現。

## 6. 制約・今後の課題

- 位相同期コントローラ（着地→整定→規定線量→凍結の1歩状態機械）による
  「速くて転ばない」の両立
- 駐機アトラクタからの自動復帰（弁開放排水の位相条件付き運用）
- エネルギー効率（現状19〜37J/90秒はGen-4比で揚水ヘッドが大きい）
- 坂道モード（下りの純受動段返り）・不整地・3D化
- 実寸部品：回転側搭載ポンプの給電（スリップリング/搭載電池）、
  フリーホイール、股コードの張力設計

## 7. 世代系譜

| 世代 | 姿勢安定 | 推進エネルギー | 特徴 |
|---|---|---|---|
| 第1（クアッド） | 能動（FC姿勢PD） | ファン水平推力 | 帯域で安定化 |
| 第2（球形気嚢） | 受動（浮力） | ファン水平推力 | 消費電力ゼロ化 |
| 第3（飛行船型） | 受動（浮力＋尾翼） | ファン水平推力 | 方向性・風見安定 |
| 第4（段返り式） | 質量幾何のみ | 水移送＋蓄圧ベローズ | 水が質量・重錘・作動流体を兼任 |
| **第5（段返り水車式）** | **質量幾何＋構え** | **水移送のみ（駆動連鎖消滅）** | タンクがクランクに乗り体ごと返る |

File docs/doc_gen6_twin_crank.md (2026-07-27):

# 第6世代：二連クランク式歩行機（ギア同期平行リンク脚）

**対応ファイル**: `gen6_walker.blend`（Gen-5モデルからの改造）/ `walker_gen6.py`
（PyBulletシミュレータ）/ `gen6_walker_walk.mp4`（90秒完走歩行の動画）。

---

## 1. 概要

Gen-5の失敗解析はすべて一点に収束した——**脚の姿勢（向き）が拘束されて
いない**。着地捕捉の失敗、ピン半径RCを伸ばしてもクリアランスが増えない相殺、
股コード・股ブレーキ・フリップロックという対症療法群は、いずれも自由振り子の
脚を間接的に躾けようとした症状だった。

Gen-6は各脚を**前後2本の同半径・同位相クランク**で吊り、**各脚内側面の
3枚ギア列**（ピン同心ギア2枚＋アイドラ、1:1同方向）で平行四辺形の位相を
全域拘束する。脚はカプラとして**並進のみ**：足は常にフラットに着地・離地し、
歩幅は2·RCで決定論的、脚質量は対で相殺してクランク釣り合いから消える。

歩行様式は転換する。機体は直立を保ち、**段返り（宙返り）はタンクを載せた
クランクだけが担う**——体ごと返るGen-5から、水車のように回るGen-6へ。

## 2. 機体構成（Gen-5からの差分）

| 要素 | 仕様 |
|---|---|
| 前方クランク | Gen-5クランク一式（タンク・中空腕・ハブポンプ/弁）をx=+0.10へ移設 |
| 後方クランク | 屈曲1回のZ形：左右ピン線（180°対向・前と同位相）＋中央の軸直角ジョグ（長さ2·RC）。中心ハブなし。**脚の貫通軸受けのみで保持（浮動）**、回転はギアが拘束 |
| ギア列 | 各脚内側面（y=∓0.105）：ピン同心ギアr=0.06×2＋脚軸支アイドラr=0.04。中心距離0.10=軸間D/2。外歯3枚=同方向1:1（2枚だと交差四辺形を強制するので不可） |
| 脚板 | 上部をz=0.45から上端へテーパー拡幅（上端±0.14m）、前後軸受けボス追加 |
| 足 | ロッカー全面更新：つま先弧**R=0.55**（h_com=0.52超）、接線位置X_TOE=+0.10、**踵平底を−0.18まで後方延長**（着地リバウンド受け） |
| 撤去機構 | 股コード・股ブレーキ・フリップロック（脚姿勢拘束により原理的に不要） |
| 総質量 | 3.86kg（Gen-5比+0.71kg：ギア6枚・後方クランク・ボス類、軽量化ギア想定） |

軸間D=0.20m。干渉はy方向の層別配置（中央ジョグ|y|<0.024／クランク腕±0.05-0.07
／ギア±0.10-0.11／脚板±0.115-0.165／タンク±0.44）で回避——全回転36姿勢×
170部品対のBVH検証で干渉ゼロ。

## 3. 動作原理

1. **構え**: 脚質量が対で相殺するため、自由平衡は「満水タンク鉛直吊り」
   （th=−atan2(R_T,DZ_T)=−0.885rad）。フリーホイール（遊び0.15rad＋掛止減衰）に
   凭れて−0.6付近に駐まり、水は軸鉛直線の後方に垂れる。**後退禁止が次の一歩の
   転倒方向を前方に確定する**（Gen-5の首オフセットと同じ役割を機構が担う）。
2. **揚水（CHARGE）**: 後方低タンクから前方高タンクへ移送。クランクが動き出した
   瞬間（|ω|>0.5）に弁凍結——**線量はフリップ開始で自動的に上限が掛かる**。
3. **反転（FLIP）**: クランクだけが半回転。機体・脚は直立のまま（ピッチ±3°）、
   基部が2·RC·cosθ≈0.13m前進し、遊脚が並進で前方へ着地。
4. **整定（SETTLE）**: 着地リバウンドをフリーホイールの遊び＋掛止減衰と延長踵が
   吸収。静穏化を検知して次のCHARGEへ。C2対称で構えが再現される。

## 4. 実験結果（PyBullet, 1/2400s, 平地, 位相同期制御）

- **全試験Q域（0.15〜0.50kg/s）で90秒間転倒ゼロ**。
- 最良点 Q=0.30：**+2.42m・18歩・クランク+53.7rad（17回転）・最大ピッチ6.8°・
  0.027m/s**。
- **1歩=0.134m＝運動学的歩幅2·RCがそのまま出る**（Gen-5のスリップ損失ゼロ）。
- 仮想ギア偏差（バックラッシュ相当）は全域≤2.4°。
- つま先弧R_TOE（0.40/0.55/0.65）は歩行性能に無影響＝**推進がつま先ロールから
  完全に分離**。ただしQ=0.30の過渡ではR=0.40が62秒で転倒、R=0.55は完走
  ——大円弧は無償の転倒保護として機能する。

## 5. 開発で確定した知見

1. **仮想ギアを股関節トルクで実装してはならない**: 反作用が前クランク軸に集中し
   正帰還で発散（0.1秒でω=9rad/s）。実機構ではピン力対のクランクトルクがギア
   経由で相殺し反力は基部へ抜ける——シミュレーションでは脚⇔基部間の外部偶力
   として実装するのが正しい。
2. **平行リンク化で構えの平衡が移動する**: 脚の重力モーメントが左右対で相殺し、
   平衡は純粋に水の吊り角で決まる。Gen-5の構え角をそのまま使うと転倒する。
3. **フリーホイールが転倒方向決定器になる**: 鉛直吊り平衡は水を持ち上げると
   方向不定になるが、後退禁止が前方を選ぶ。
4. **着地リバウンドの吸収系が必須**: 過回転の跳ね返り→硬い掛止→基部後傾→
   踵後端越えの後方転倒が唯一の転倒モードだった。ラチェット遊び0.15＋掛止減衰
   ＋踵後方延長で根絶（踵は平底のまま延長：Gen-5知見「踵平底不可侵」と両立）。
5. **リンク（サイドロッド）のみの平行拘束は死点で破綻し得る**: クランク水平で
   左右同時に一直線（180°対向のためクォータリング不可）。ギア列・チェーンは
   角度そのものを拘束するため死点が存在しない。3枚（同方向）が必須。
6. **線量制御は位相機械に統合される**: CHARGE→FLIP遷移（クランク始動検知）が
   「ちょうど返る分だけ」の移送を自動実現。無制御の前方移送則は全水量集中→
   過大フリップ→転倒（Gen-5知見の駐機アトラクタの終着形）。
7. **後方クランクの中央軸受け支持は幾何学的に不可**: ピン掃引（|y|=0.01〜0.19）と
   ジョグ掃引（|y|<0.024）が回転面を埋め、基部からの支持ブラケットの通り道が
   ない。浮動＋ギア拘束が正解。

## 6. 制約・今後の課題

- 歩行速度0.027m/s：歩周期約5秒はSETTLE整定（0.8s）とCHARGE移送時間が支配的。
  整定条件の短縮・Q最適化・RC=0.09（歩幅+29%）の検証
- エネルギー約5.4J/歩（Q=0.30・90秒で97J）の低減
- 実機ギアの軽量化（ソリッド金属では6枚で2kg超——ウェブ抜き・樹脂化の設計）
- 円弧軌道接地に固有の着地スカッフ（ロッカーで緩和済みだが残存）
- クランク反動トルクが機体を通る経路（Gen-4系）の定量化
- 防衛公開：ギア同期平行クランク脚案内は歩行玩具・機関車連結棒に連なる古典
  機構の組み合わせであり、先行技術欄への追記が必要

## 7. 世代系譜

| 世代 | 姿勢安定 | 推進エネルギー | 特徴 |
|---|---|---|---|
| 第1（クアッド） | 能動（FC姿勢PD） | ファン水平推力 | 帯域で安定化 |
| 第2（球形気嚢） | 受動（浮力） | ファン水平推力 | 消費電力ゼロ化 |
| 第3（飛行船型） | 受動（浮力＋尾翼） | ファン水平推力 | 方向性・風見安定 |
| 第4（段返り式） | 質量幾何のみ | 水移送＋蓄圧ベローズ | 水が質量・重錘・作動流体を兼任 |
| 第5（段返り水車式） | 質量幾何＋構え | 水移送のみ | タンクがクランクに乗り体ごと返る |
| **第6（二連クランク式）** | **質量幾何＋脚姿勢の機構拘束** | **水移送のみ** | ギア同期平行リンクで足が常にフラット、機体直立・歩幅決定論、全Q域転倒ゼロ |

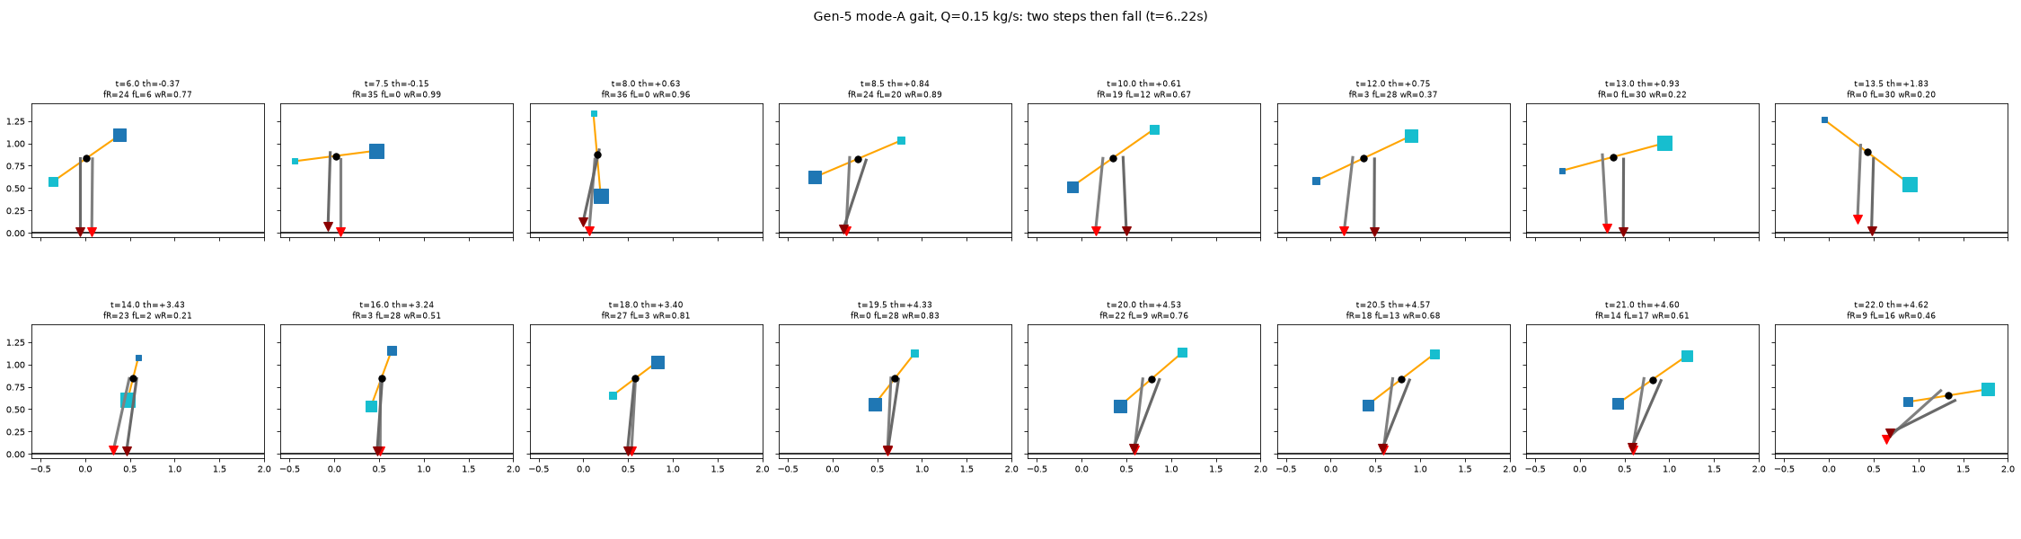
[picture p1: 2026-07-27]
media/gen5_gait_strip.png

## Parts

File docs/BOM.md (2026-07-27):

# 参考部品表 / Reference Bill of Materials

**注意**: 本プロジェクトはシミュレーション検証済みの設計データであり、実機は未製作。
本表はモデル寸法（`hardware/drawings/` の図面値）に基づく参考構成である。
材料・調達品は例示であり、質量収支（右列）を満たす範囲で代替可。

質量収支の根拠は `sim/walker_*.py` のパラメータ（M_TORSO / M_TH / M_SH / M_BAL）。

## 共通: 脚系（全世代、図面 gen1_shank_inner / gen1_thigh_outer 参照）

| # | 部品 | 主要寸法 (mm) | 数量 | 材料例 | 質量目標 |
|---|---|---|---|---|---|
| L1 | 大腿シャフト（内脚） | φ42 × L380 | 2 | CFRPパイプ | 計 0.22 kg（内大腿対） |
| L2 | 大腿シャフト（外脚） | φ42 × L523 | 2 | CFRPパイプ | 計 0.22 kg（外大腿対） |
| L3 | ヨークアーチ | φ24 × 展開長 ~420 | 1 | CFRP曲げ管 | L2に含む |
| L4 | 下腿シャフト | φ36 × L360 | 4 | CFRPパイプ | 各対 0.20 kg |
| L5 | 円弧足 | R120 × W80（前方オフセット +40） | 4 | 積層合板 or 3Dプリント | L4に含む |
| L6 | 膝反張ストッパ | 停止角 +0.08 rad、リカーブ付 | 4 | アルミ削り出し | — |
| L7 | 股・膝ヒンジ軸受 | フリーヒンジ（無動力） | 8 | ボールベアリング | — |

膝ラッチは実装方式自由（実機では機械式オーバーセンターラッチ＋小型サーボ解放を想定）。
制御ロジックの正は `sim/` の状態機械（接地力8N・股関節角−0.08 radゲート等）。

## Gen-1: クアッドロータトルソ（図面 gen1_torso_quad）

| # | 部品 | 主要寸法 (mm) | 数量 | 質量目標 |
|---|---|---|---|---|
| T1 | 股関節車軸 | φ56 × L460 | 1 | トルソ計 1.2 kg |
| T2 | プラットフォーム | 260 × 300 × 45 | 1 | 〃 |
| T3 | アーム | φ26、先端 (±310, ±310) | 4 | 〃 |
| T4 | プロペラ（2枚ブレード） | D200、ピッチ15°、CW/CCW交互 | 4 | 〃 |
| T5 | FC＋ESC＋バッテリ | 姿勢PD kp80/kd10、高度支持なし | 1式 | 〃 |

## Gen-2: バルーン＋アジマスファン（図面 gen2_torso_fan / gen2_mast_balloon）

| # | 部品 | 主要寸法 (mm) | 数量 | 質量目標 |
|---|---|---|---|---|
| B1 | ダクテッドファン | ダクト外径202・幅56、プロペラD156 | 2 | トルソ計 1.4 kg |
| B2 | アジマス旋回機構 | z軸旋回 | 2 | 〃 |
| B3 | マスト | φ30 × z910–1962 | 1 | 気嚢系 0.25 kg |
| B4 | 気嚢（球） | モデルØ1000 / **実機Ø≈1400（He 1.3 m³, B=13 N）** | 1 | 〃 |

## Gen-3: 飛行船型気嚢＋門型マスト（図面 gen3_hull_tail / gen3_portal_mast）

| # | 部品 | 主要寸法 (mm) | 数量 | 質量目標 |
|---|---|---|---|---|
| A1 | 気嚢（回転楕円体） | L2200 × D900（フィネス比2.4）/ 実機は約1.3 m³必要 | 1 | 気嚢系 0.30 kg |
| A2 | 尾翼 | 400 × 370 × t12、十字4枚、根元r200–先端r570 | 4 | 〃 |
| A3 | 門型マスト支柱 | φ24、y=±300、z910–1040 | 2 | 〃 |
| A4 | クロスバー＋斜材 | φ24 span624 @z1040 / φ20 → 頂点z1260 | 1式 | 〃 |
| A5 | 単管 | φ30、z1260–1937（気嚢腹部へ） | 1 | 〃 |
| A6 | ダクテッドファン一式 | Gen-2のB1/B2と共通 | 2 | 1.4 kg |

## 全体質量収支（設計値）

| 世代 | 総質量 | 総重量 | 浮力/推力条件 |
|---|---|---|---|
| Gen-1 | 2.24 kg | 22.0 N | 姿勢PDのみ、KZ=0、KV≥4–5 |
| Gen-2 | 2.49 kg | 24.4 N | B=13 N（53%W）推奨、窓37–94%W |
| Gen-3 | 2.54 kg | 24.9 N | B=13 N（52%W）推奨 |

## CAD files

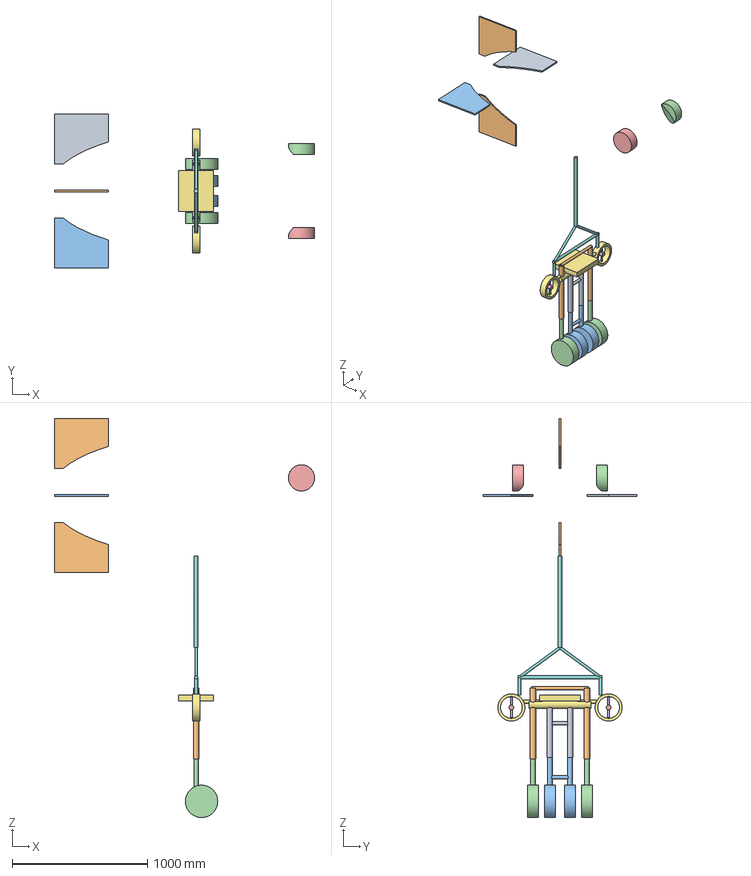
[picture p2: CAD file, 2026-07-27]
hardware/cad/gen3_walker.step
1927.0 x 1140.0 x 2954.8 mm

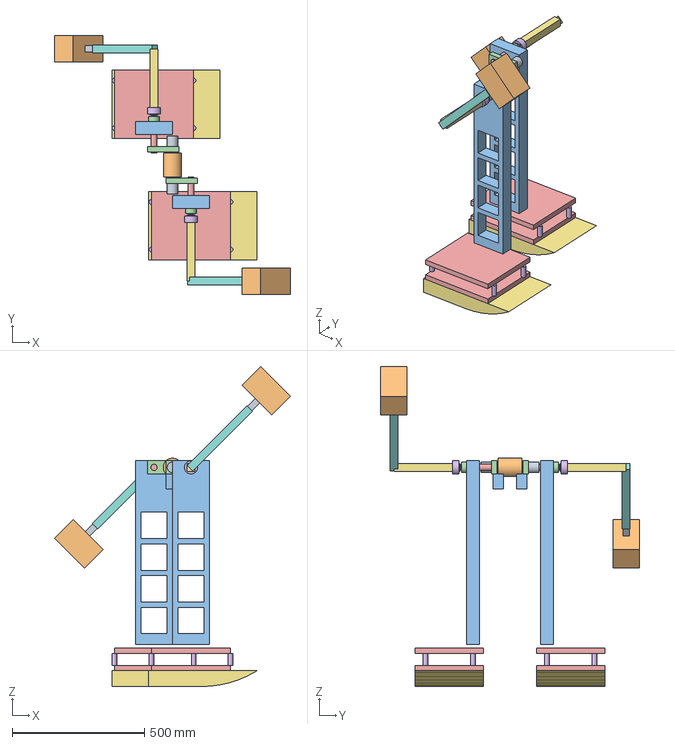
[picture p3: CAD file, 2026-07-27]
hardware/cad/gen5_walker.step
893.8 x 980.0 x 1211.9 mm

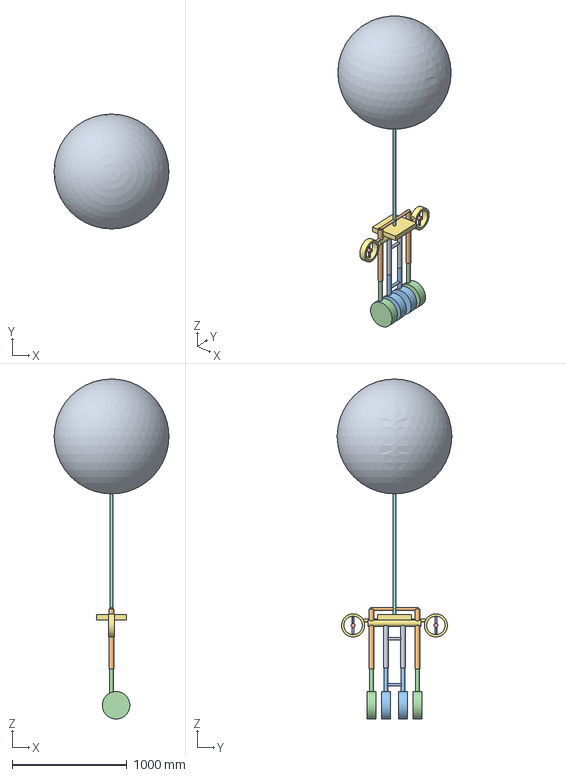
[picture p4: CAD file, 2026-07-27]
hardware/cad/gen2_walker.step
1000.0 x 1000.0 x 2959.8 mm

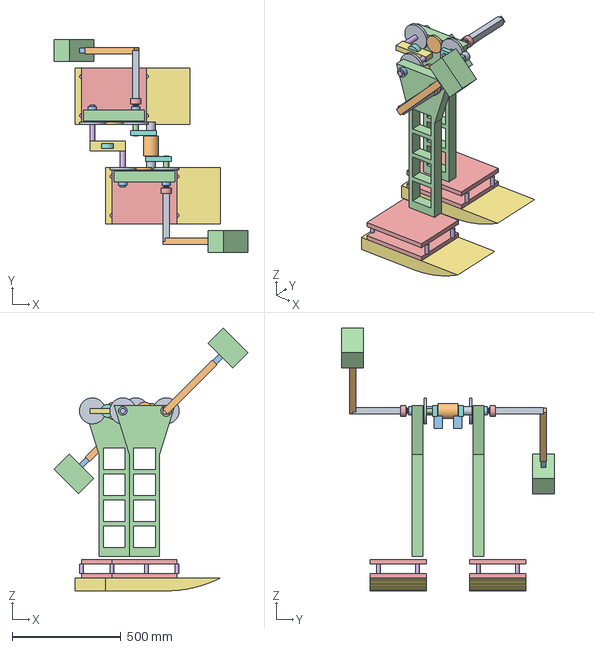
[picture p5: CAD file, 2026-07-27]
hardware/cad/gen6_walker.step
893.8 x 980.0 x 1211.9 mm

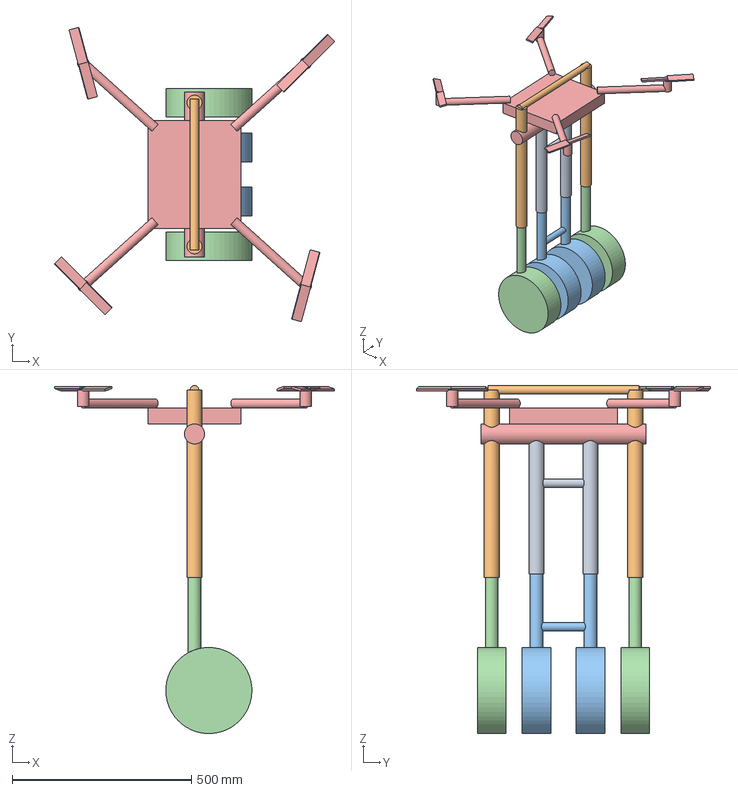
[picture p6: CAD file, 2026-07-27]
hardware/cad/gen1_walker.step
781.6 x 820.6 x 969.8 mm

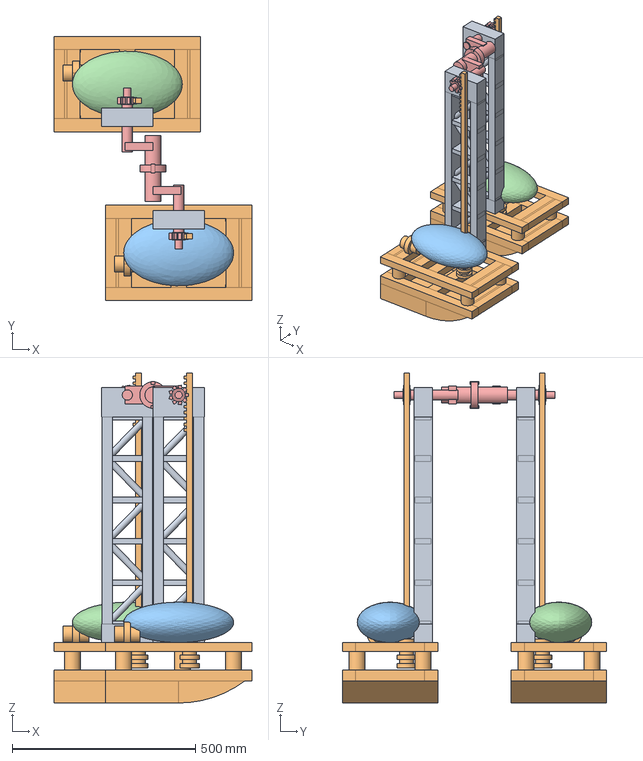
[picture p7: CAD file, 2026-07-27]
hardware/cad/gen4_walker.step
540.0 x 720.0 x 900.0 mm

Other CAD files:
hardware/cad/gen1_walker.FCStd
hardware/cad/gen2_walker.FCStd
hardware/cad/gen3_walker.FCStd
hardware/cad/gen4_walker.FCStd
hardware/cad/gen5_walker.FCStd
hardware/cad/gen6_walker.FCStd
viz/gen1_drone_walker_attitude_only.blend
viz/gen2_balloon_walker.blend
viz/gen3_airship_walker_face.blend
viz/gen4_dankaeri_walker.blend
viz/gen5_walker.blend
viz/gen6_walker.blend

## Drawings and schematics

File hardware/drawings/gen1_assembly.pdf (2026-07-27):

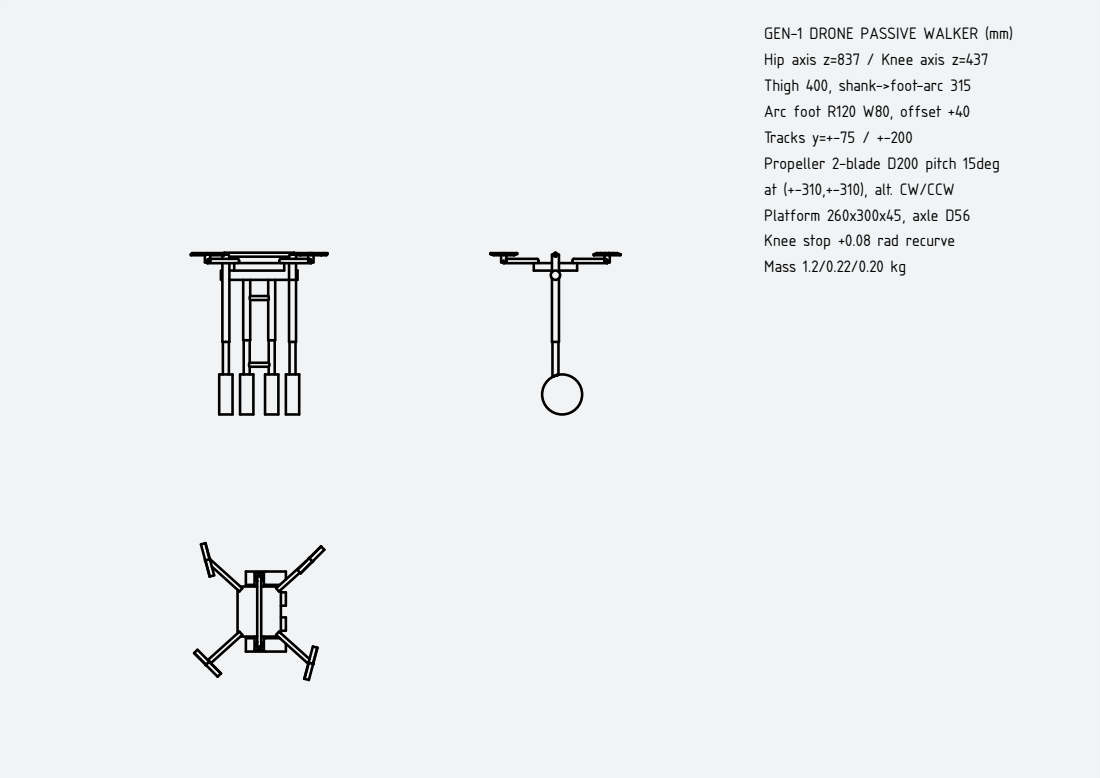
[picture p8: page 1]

GEN-1 DRONE PASSIVE WALKER (mm)
Hip axis z=837 / Knee axis z=437
Thigh 400, shank->foot-arc 315
Arc foot R120 W80, offset +40
Tracks y=+-75 / +-200
Propeller 2-blade D200 pitch 15deg
at (+-310,+-310), alt. CW/CCW
Platform 260x300x45, axle D56
Knee stop +0.08 rad recurve
Mass 1.2/0.22/0.20 kg

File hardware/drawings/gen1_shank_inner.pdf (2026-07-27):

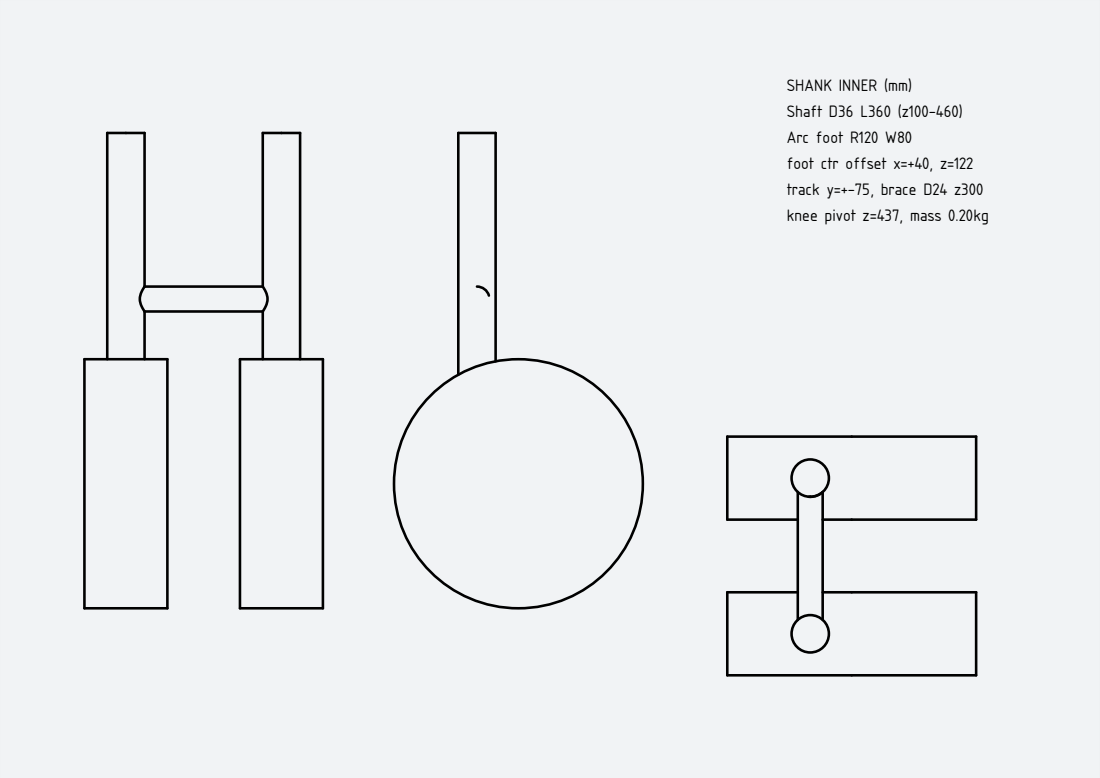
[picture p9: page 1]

SHANK INNER (mm)
Shaft D36 L360 (z100-460)
Arc foot R120 W80
foot ctr offset x=+40, z=122
track y=+-75, brace D24 z300
knee pivot z=437, mass 0.20kg

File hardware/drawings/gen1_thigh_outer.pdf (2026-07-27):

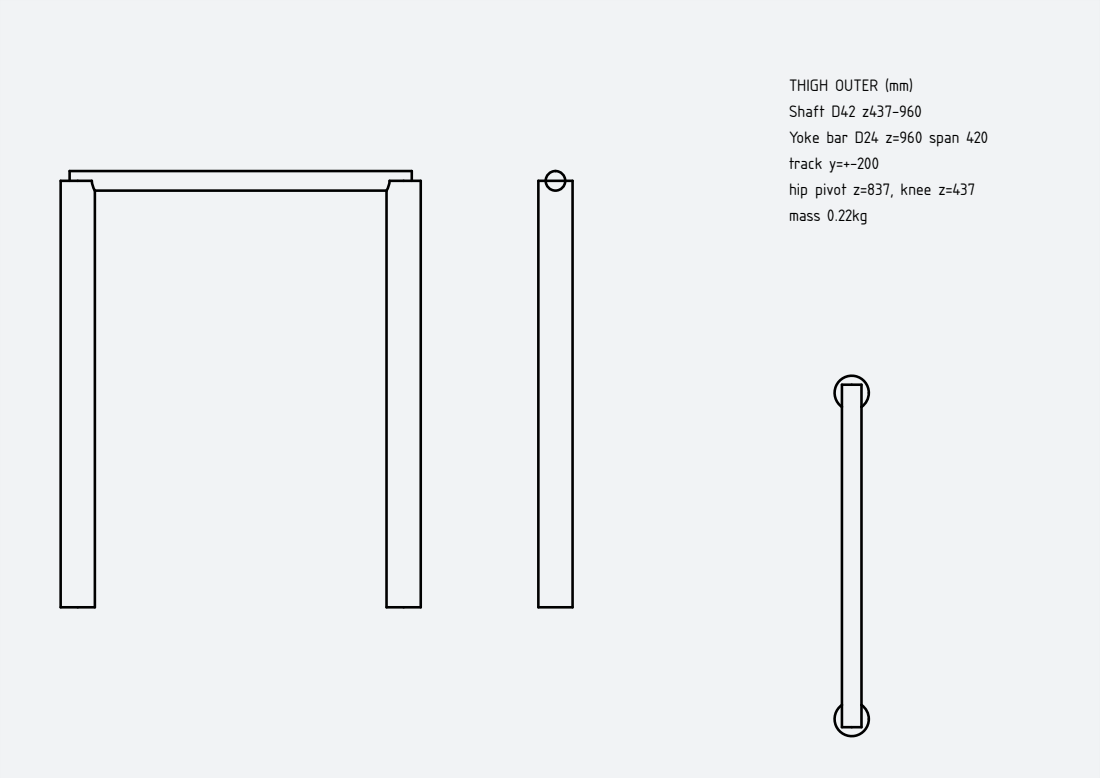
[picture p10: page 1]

THIGH OUTER (mm)
Shaft D42 z437-960
Yoke bar D24 z=960 span 420
track y=+-200
hip pivot z=837, knee z=437
mass 0.22kg

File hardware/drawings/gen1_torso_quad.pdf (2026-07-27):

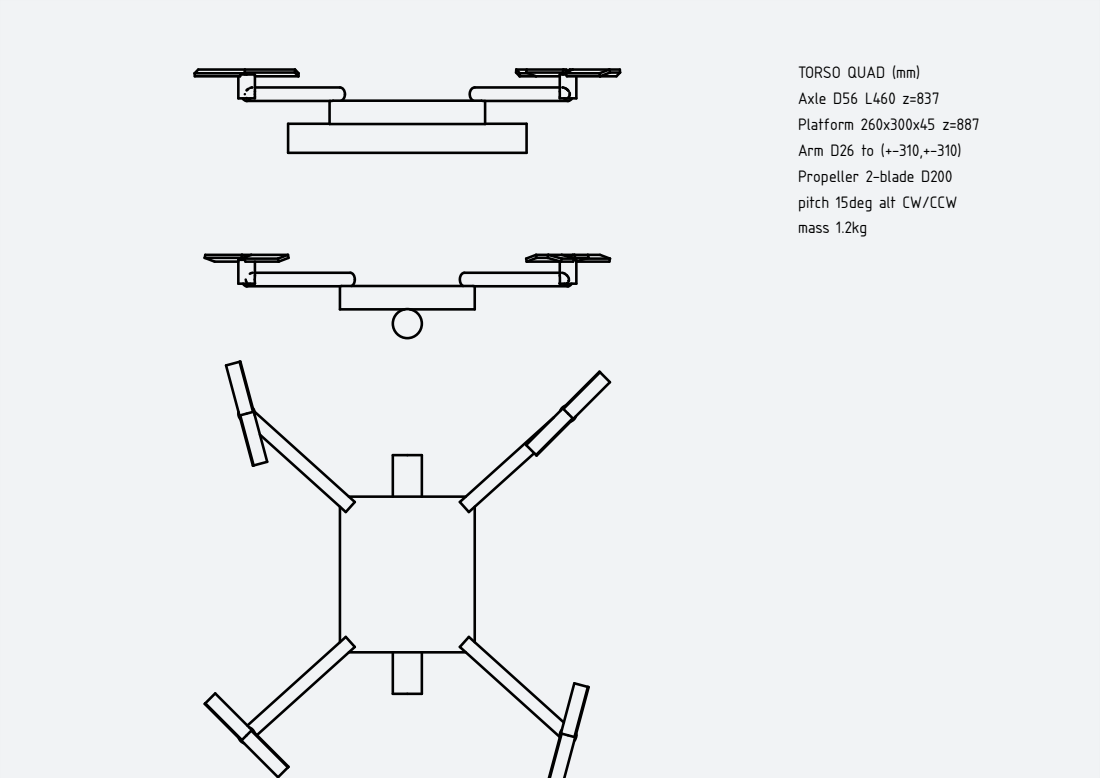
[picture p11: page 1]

TORSO QUAD (mm)
Axle D56 L460 z=837
Platform 260x300x45 z=887
Arm D26 to (+-310,+-310)
Propeller 2-blade D200
pitch 15deg alt CW/CCW
mass 1.2kg

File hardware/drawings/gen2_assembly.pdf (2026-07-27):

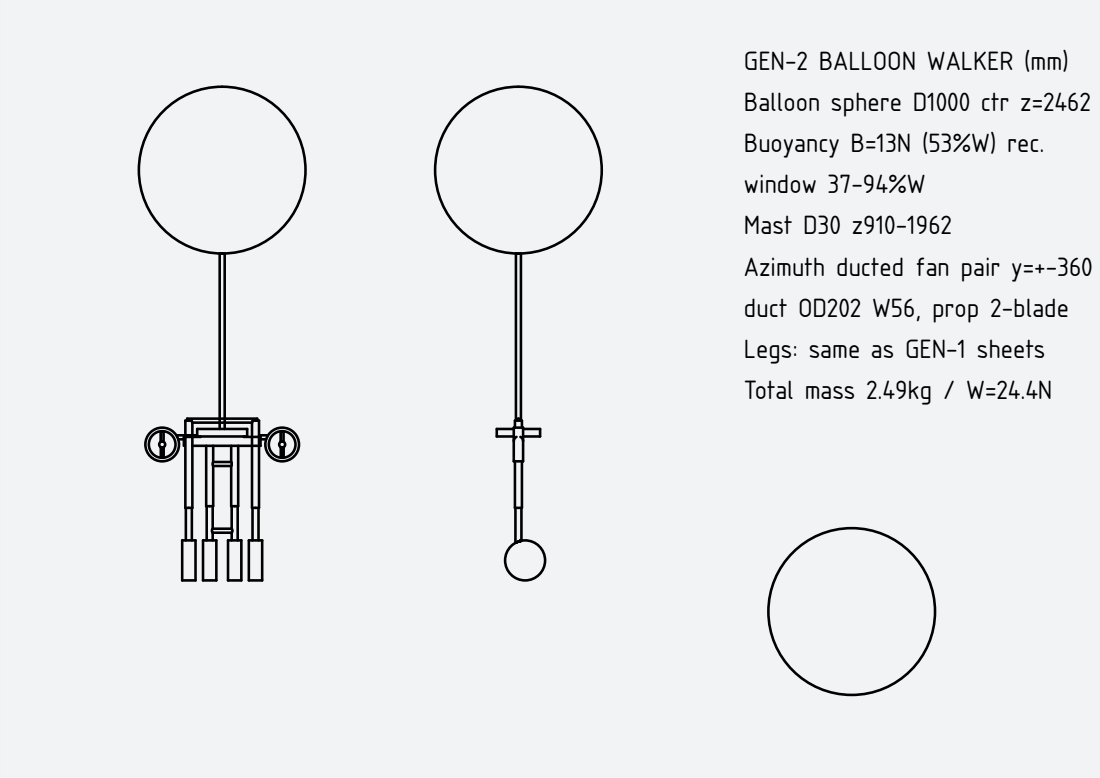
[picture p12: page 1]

GEN-2 BALLOON WALKER (mm)
Balloon sphere D1000 ctr z=2462
Buoyancy B=13N (53%W) rec.
window 37-94%W
Mast D30 z910-1962
Azimuth ducted fan pair y=+-360
duct OD202 W56, prop 2-blade
Legs: same as GEN-1 sheets
Total mass 2.49kg / W=24.4N

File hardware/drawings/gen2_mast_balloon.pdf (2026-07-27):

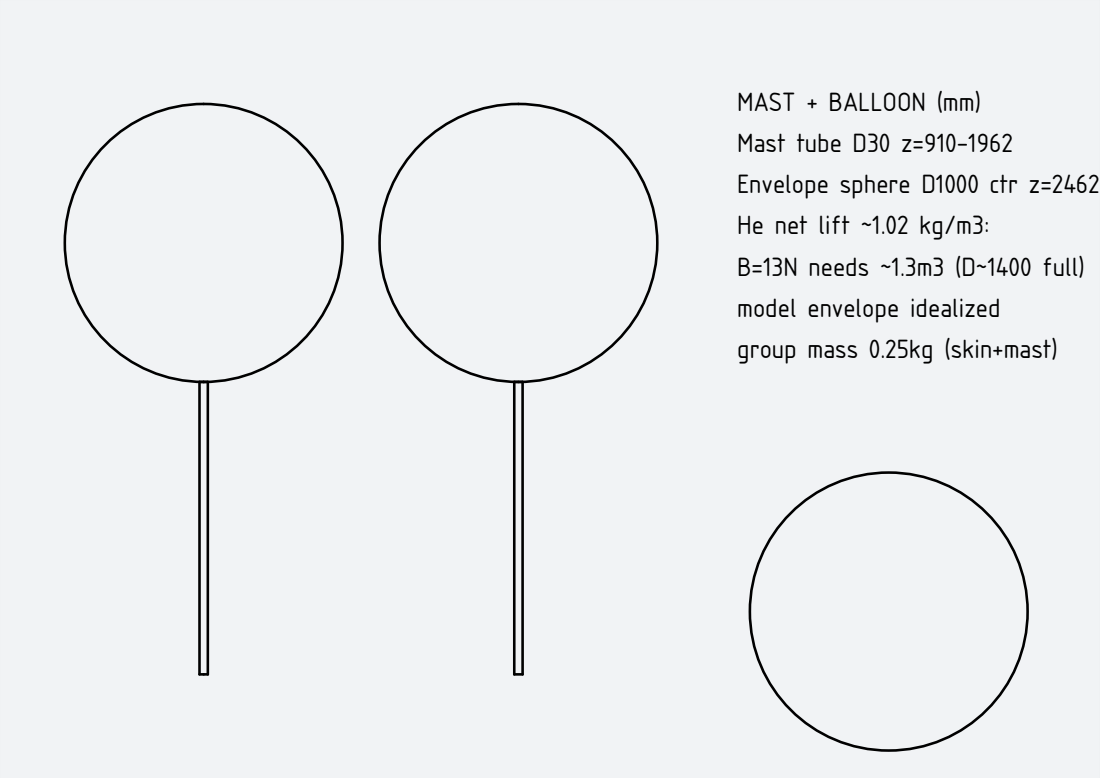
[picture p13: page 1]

MAST + BALLOON (mm)
Mast tube D30 z=910-1962
Envelope sphere D1000 ctr z=2462
He net lift ~1.02 kg/m3:
B=13N needs ~1.3m3 (D~1400 full)
model envelope idealized
group mass 0.25kg (skin+mast)

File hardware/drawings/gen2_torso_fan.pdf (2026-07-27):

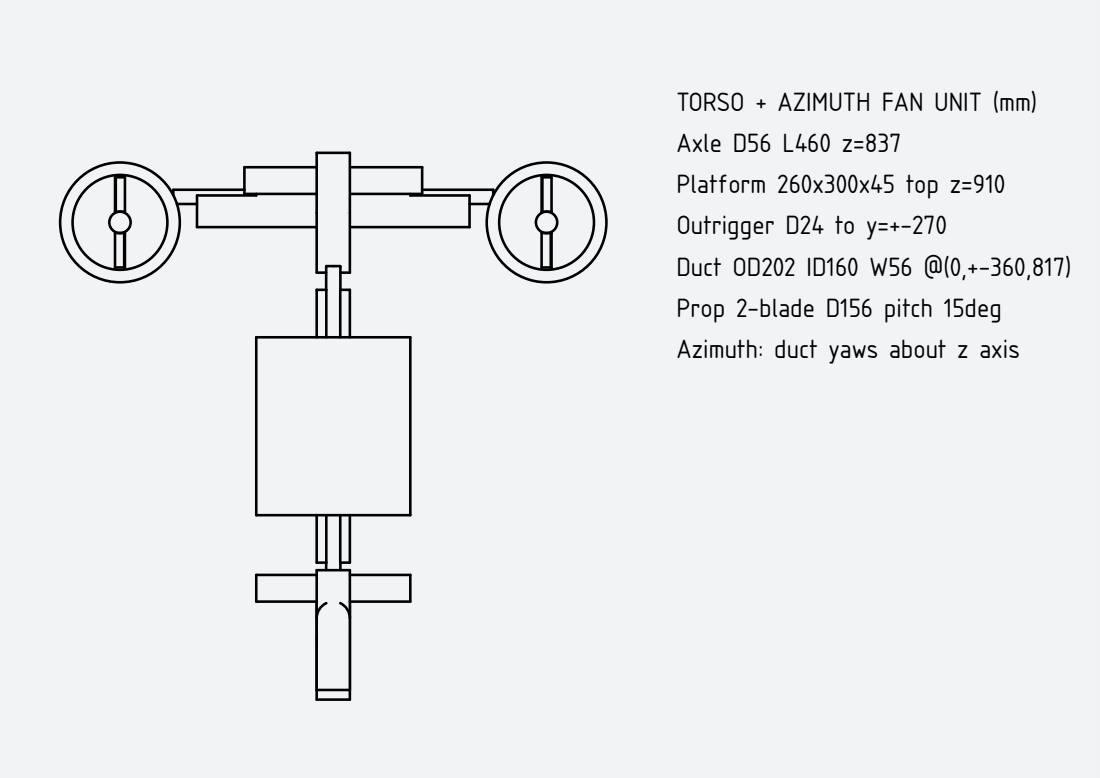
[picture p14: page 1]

TORSO + AZIMUTH FAN UNIT (mm)
Axle D56 L460 z=837
Platform 260x300x45 top z=910
Outrigger D24 to y=+-270
Duct OD202 ID160 W56 @(0,+-360,817)
Prop 2-blade D156 pitch 15deg
Azimuth: duct yaws about z axis

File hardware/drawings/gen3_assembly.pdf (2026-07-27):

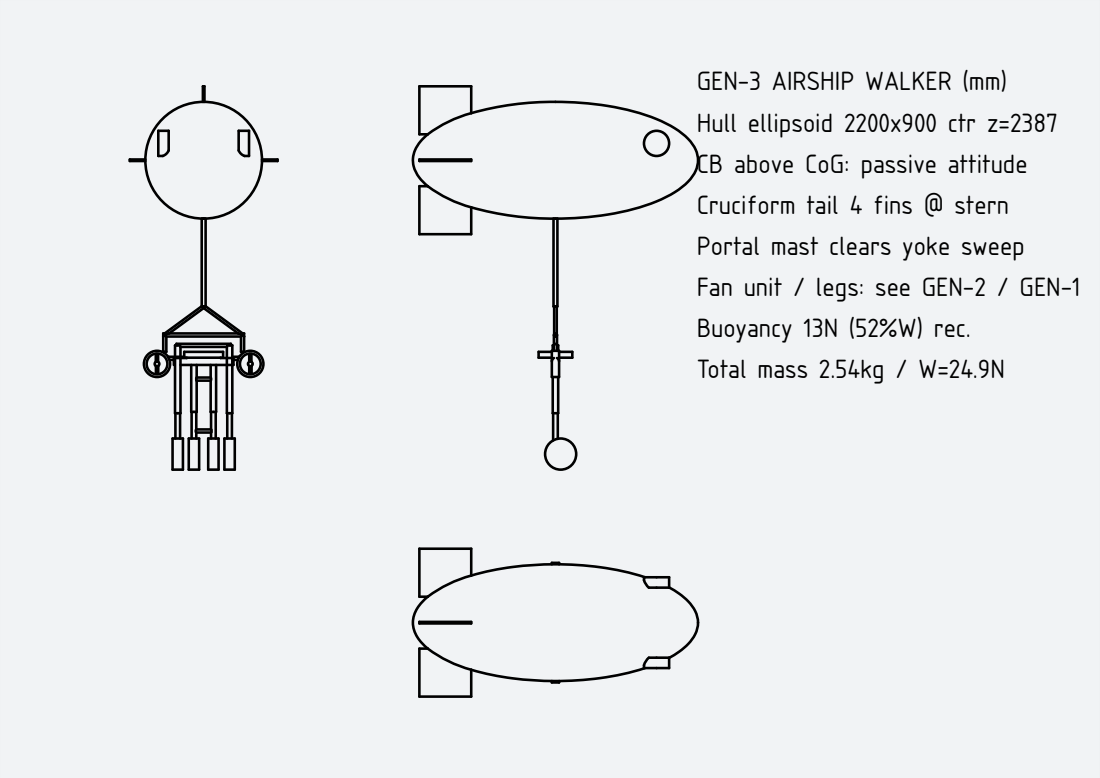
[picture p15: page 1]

GEN-3 AIRSHIP WALKER (mm)
Hull ellipsoid 2200x900 ctr z=2387
CB above CoG: passive attitude
Cruciform tail 4 fins @ stern
Portal mast clears yoke sweep
Fan unit / legs: see GEN-2 / GEN-1
Buoyancy 13N (52%W) rec.
Total mass 2.54kg / W=24.9N

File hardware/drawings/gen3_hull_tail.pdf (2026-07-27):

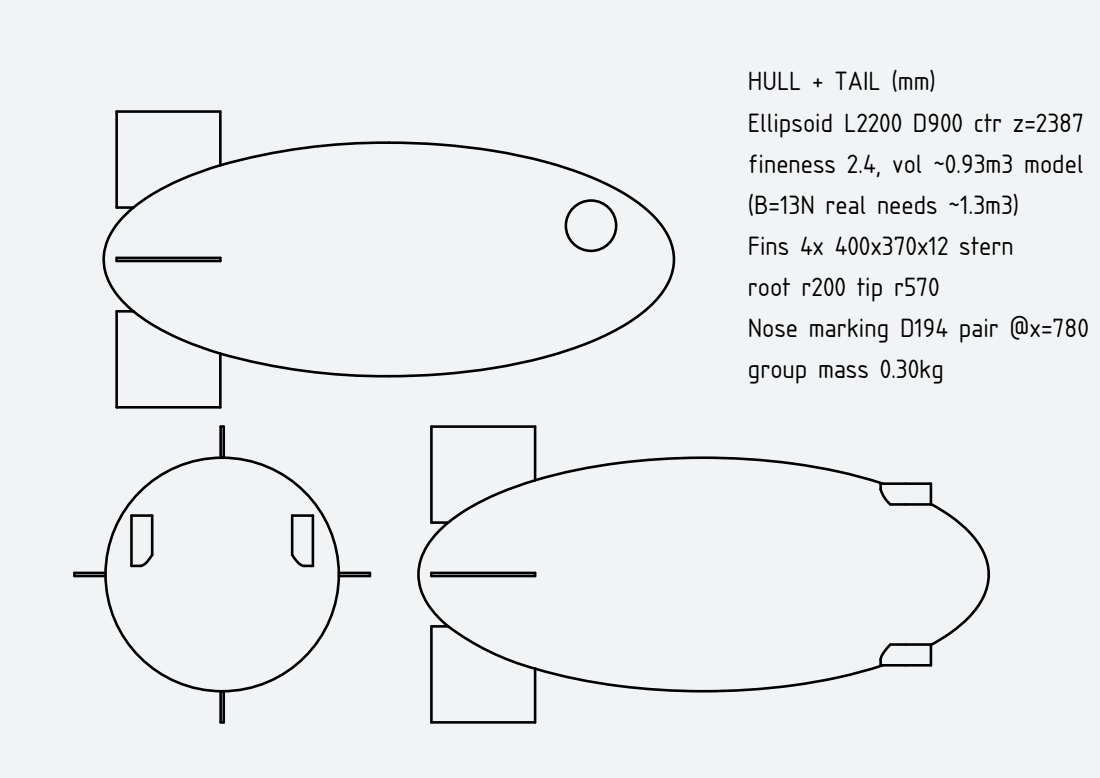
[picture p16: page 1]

HULL + TAIL (mm)
Ellipsoid L2200 D900 ctr z=2387
fineness 2.4, vol ~0.93m3 model
(B=13N real needs ~1.3m3)
Fins 4x 400x370x12 stern
root r200 tip r570
Nose marking D194 pair @x=780
group mass 0.30kg

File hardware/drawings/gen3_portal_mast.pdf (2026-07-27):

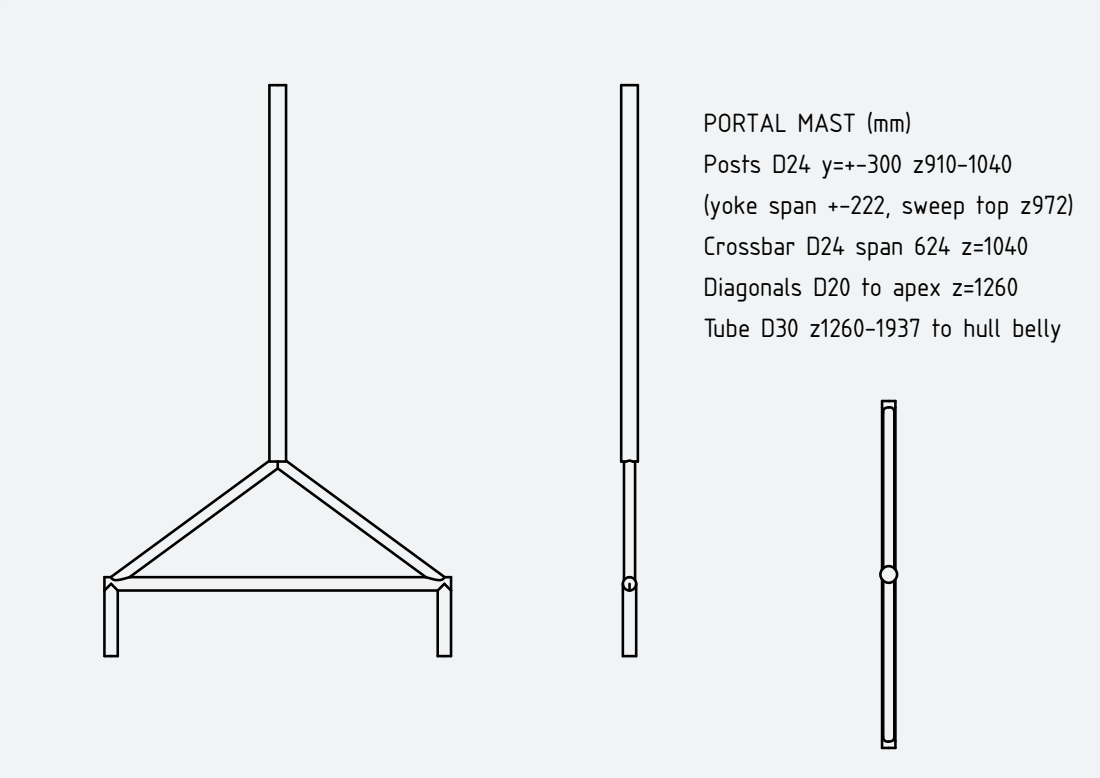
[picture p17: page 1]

PORTAL MAST (mm)
Posts D24 y=+-300 z910-1040
(yoke span +-222, sweep top z972)
Crossbar D24 span 624 z=1040
Diagonals D20 to apex z=1260
Tube D30 z1260-1937 to hull belly

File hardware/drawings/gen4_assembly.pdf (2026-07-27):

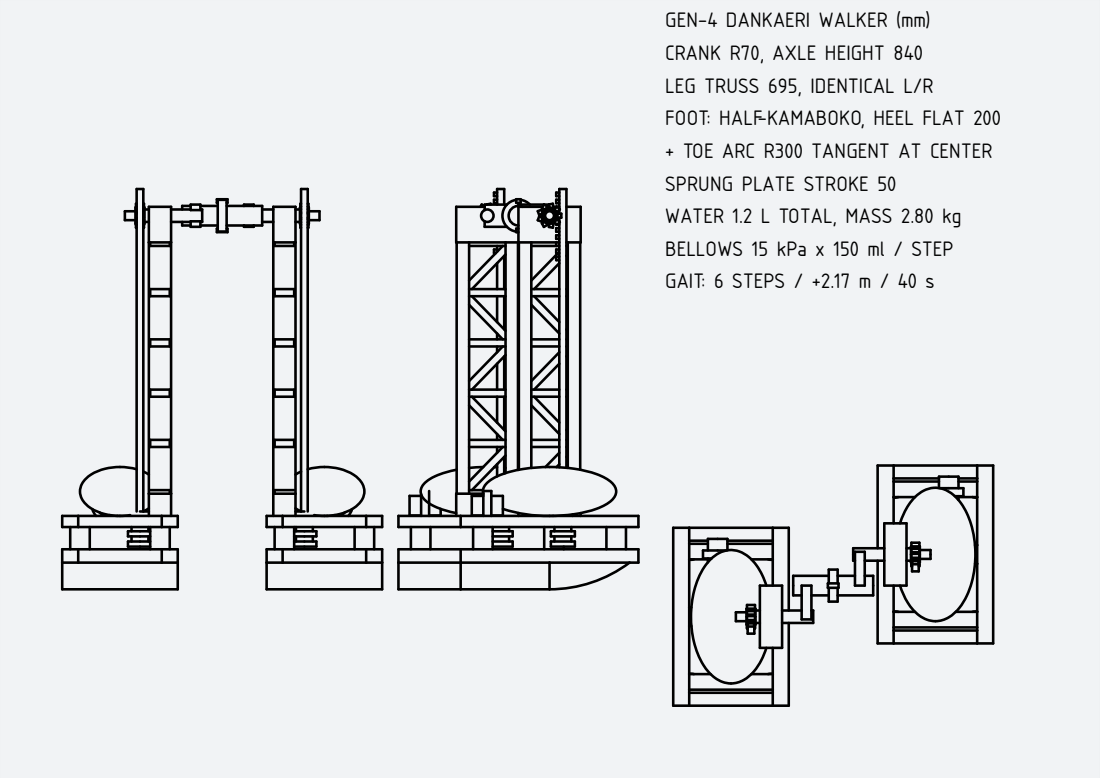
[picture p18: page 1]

GEN-4 DANKAERI WALKER (mm)
CRANK R70, AXLE HEIGHT 840
LEG TRUSS 695, IDENTICAL L/R
FOOT: HALF-KAMABOKO, HEEL FLAT 200
+ TOE ARC R300 TANGENT AT CENTER
SPRUNG PLATE STROKE 50
WATER 1.2 L TOTAL, MASS 2.80 kg
BELLOWS 15 kPa x 150 ml / STEP
GAIT: 6 STEPS / +2.17 m / 40 s

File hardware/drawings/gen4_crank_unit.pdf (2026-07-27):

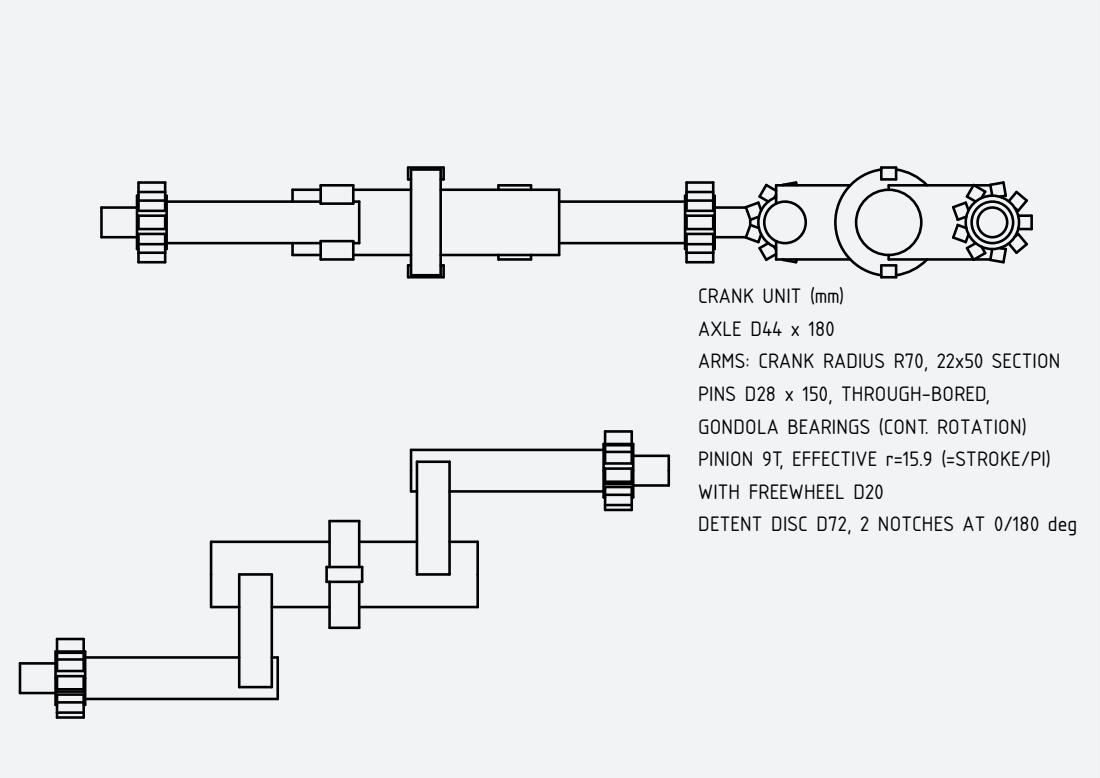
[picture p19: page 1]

CRANK UNIT (mm)
AXLE D44 x 180
ARMS: CRANK RADIUS R70, 22x50 SECTION
PINS D28 x 150, THROUGH-BORED,
GONDOLA BEARINGS (CONT. ROTATION)
PINION 9T, EFFECTIVE r=15.9 (=STROKE/PI)
WITH FREEWHEEL D20
DETENT DISC D72, 2 NOTCHES AT 0/180 deg
